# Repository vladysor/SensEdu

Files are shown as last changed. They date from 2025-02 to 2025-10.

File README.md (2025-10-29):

<p align="center">
  
</p>

<p align="center"><b>Ultrasonic Ranging & Detection Development Shield for Arduino GIGA R1</b><br>
Designed for education - easy entry into ultrasonic sensing and research</p>

<p align="center">
  <a href="https://github.com/ShiegeChan/SensEdu/releases/" target="_blank">
    
  </a>
  <a href="https://github.com/ShiegeChan/SensEdu/commits/main" target="_blank">
    
  </a>
</p>

<b>
<p align="center">
	<a href="https://github.com/ShiegeChan/SensEdu/releases" target="_blank">Download</a> ·
	<a href="https://shiegechan.github.io/SensEdu/getting-started/" target="_blank">Getting Started</a> ·
	<a href="https://shiegechan.github.io/SensEdu/projects/" target="_blank">Example Projects</a> ·
	<a href="https://shiegechan.github.io/SensEdu/" target="_blank">Documentation</a> ·
	<a href="https://shiegechan.github.io/SensEdu/contributing/" target="_blank">Contribution</a>
</p>
</b>

## Features

* **Custom Shield Design** for <a href="https://docs.arduino.cc/hardware/giga-r1-wifi/?queryID=undefined" target="_blank">Arduino GIGA R1 WiFi</a> and mechanically compatible boards (e.g., <a href="https://www.infineon.com/evaluation-board/KIT-A2G-TC375-ARD-SB" target="_blank">AURIX™ TC375 Shieldbuddy</a>). It extends the board with sensors:
  * **4x Infineon MEMS microphones**: capable of operating in ultrasonic range at approx. 20-80 kHz (<a href="https://www.infineon.com/assets/row/public/documents/24/49/infineon-im73a135-datasheet-en.pdf" target="_blank">datasheet</a>).
  * **2x Ultrasonic Transducers**: transmit ultrasonic waves with a center frequency of ~33kHz (<a href="https://www.farnell.com/datasheets/4413630.pdf?_gl=1*1fltz5c*_gcl_au*MTQwMTY3ODgxOC4xNzI2NDc2MDYw" target="_blank">datasheet</a>).
  * **2x Instrumentation Amplifiers**: providing 4x channels total, routed to external pin headers for connecting additional sensors such as surface EMG electrodes (<a href="https://www.analog.com/media/en/technical-documentation/data-sheets/ad8222.pdf" target= "_blank">datasheet</a>).
  * **1x Infineon Barometric Air Pressure Sensor**: provides pressure and temperature measurements; ideal for indoor and outdoor navigation, weather stations, drones, and more (<a href="https://www.infineon.com/dgdl/Infineon-DPS310-DataSheet-v01_02-EN.pdf?fileId=5546d462576f34750157750826c42242" target="_blank">datasheet</a>).
* **Low-Level SensEdu Library** for Arduino GIGA R1 that serves as a basic abstraction layer for the STM32H747 peripherals and provides default configurations for all sensors. It is implemented at the register level based on <a href="https://www.st.com/resource/en/reference_manual/rm0399-stm32h745755-and-stm32h747757-advanced-armbased-32bit-mcus-stmicroelectronics.pdf" target="_blank">STM32H747 Reference Manual</a> and <a href="https://developer.arm.com/documentation/ddi0403/latest/" target="_blank"> Armv7-M Architecture Reference Manual</a>, ensuring simplicity and expandability. Extensive examples are included to demonstrate library's functionality.
* **Example projects** show how to use SensEdu to achieve your learning goals. See the full implementation for pulsed time-of-flight distance measurements, FMCW ranging, FSK-modulated communication, a weather station, and other projects.
* **MATLAB scripts** enable visualization and post-processing of recorded data transferred via USB or Wi-Fi.

## Preview

<p align="center" style="margin:0">
  
  
  
  
  
</p>

## Installation

1. Download the latest release version from the <a href="https://github.com/ShiegeChan/SensEdu/releases" target="_blank">Download page</a>.
2. Extract the downloaded files and place the **libraries** folder into: `C:\Users\your_username\Documents\Arduino\`.
3. The **projects** folder can be placed anywhere in your system.
4. Open the <a href="https://www.arduino.cc/en/software" target="_blank">Arduino IDE</a> and install **Arduino Giga R1 board package** via the Boards Manager.

<p align="left" style="margin:0">
  
</p>
<p align="left" style="margin:0">
  
</p>

## Starting a Project

To get started, you can explore the hardware interface by following the examples provided in the SensEdu library (`Arduino\libraries\SensEdu\examples\`). A detailed description of all functions can be found in the <a href="https://shiegechan.github.io/SensEdu/library/" target="_blank">Documentation</a> under the "SensEdu Library" section.

In the `projects/` directory, you will find several complete projects designed for this board, including:
* **Ultrasonic Pulse-Echo Ranging**
* **Ultrasonic Pulse-Echo Ranging with Wi-Fi + GUI** - *in progress (25%)*
* **Ultrasonic Chirp Generation**
* **Ultrasonic FMCW Ranging**
* **Ultrasonic Doppler Velocimeter** - *coming soon*
* **Ultrasonic FSK Communication Link** - *coming soon*
* **EMG BioInputs** - *in progress (75%)*
* **Weather Station** - *in progress (50%)*

Detailed overview for each project is available in the "Projects" section of the <a href="https://shiegechan.github.io/SensEdu/projects/" target="_blank">Documentation</a>.

## Support

If you would like to contribute, please open a pull request!
Suggest improvements or check out already opened <a href="https://github.com/ShiegeChan/SensEdu/issues" target="_blank">issues</a> to help fix bugs or add new features.

## Acknowledgments

SensEdu was made possible thanks to these freely available tools:

* [Arduino] and [Arduino IDE 2.x]
* [XENSIV™ Digital Pressure Sensor Arduino Library]
* [STM32H747 Documentation] and [STM32CubeMX]
* [Jekyll] and [Just the Docs] template
* [KiCAD]

## License

* [**GPL-3.0 license**](https://github.com/ShiegeChan/SensEdu/blob/main/LICENSE)

[Arduino IDE 2.x]: https://github.com/arduino/arduino-ide
[Arduino]: https://www.arduino.cc/
[XENSIV™ Digital Pressure Sensor Arduino Library]: https://github.com/Infineon/arduino-xensiv-dps3xx
[STM32H747 Documentation]: https://www.st.com/en/microcontrollers-microprocessors/stm32h747-757/documentation.html
[STM32CubeMX]: https://www.st.com/en/development-tools/stm32cubemx.html
[Jekyll]: https://jekyllrb.com/
[Just the Docs]: https://github.com/just-the-docs/just-the-docs/tree/main
[STM32H747]: https://www.st.com/en/microcontrollers-microprocessors/stm32h747-757.html
[Arduino GIGA R1 WiFi]: https://docs.arduino.cc/hardware/giga-r1-wifi/
[KiCad]: https://www.kicad.org/

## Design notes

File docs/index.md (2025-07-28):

---
title: Introduction
layout: home
nav_order: 1
description: "SensEdu is an educational development shield for Arduino GIGA R1 used for RADAR and communications applications."
permalink: /
---

# Introduction
{: .fs-8 .fw-500}

Welcome to the SensEdu documentation!
{: .fs-6 .fw-400}
---

SensEdu is an educational project designed to simplify entry into RADAR and communications research.
{: .fw-500}

Based on the [STM32H747] Microcontroller and runs on the [Arduino GIGA R1 WiFi] development Board, providing industry-standard embedded development experience while remaining beginner-friendly. SensEdu is perfect for students looking for a smooth introduction to this field, offering an easy-to-understand yet highly modifiable software and hardware environment. 

This project is completely open source and comes with quick support from the development team.

{: .WARNING}
SensEdu is still in its early development stages.
The core functionality is available, but many additional features are in progress. If you like the project, consider [contributing]({% link Contributing/index.md %}). Any input from both experienced developers and beginners is highly appreciated!

## Features
{: .fw-500}

SensEdu includes:
{:.mb-1 .mt-3}
* MEMS microphones
* Barometric Air Pressure Sensor
* Ultrasonic Transducers

You can find detailed information about each component in the [PCB Chapter]({% link PCB/index.md %}). With these components, you can build a variety of projects, such as:
* Ultrasonic Distance Measurements
* Chirp Signal Generation
* FMCW Radars
* Frequency Shift Keying (FSK) communication between multiple boards
* Weather Stations

## Project Structure
{: .fw-500}

The project is divided into three main parts:

* [Shield PCB]({% link PCB/index.md %}) – Located in `pcb\`
* [Hardware Abstraction Library]({% link Library/index.md %}) – Located in `libraries\SensEdu\`
* [Full Projects]({% link Projects/index.md %}) – Located in `projects\`

Each part is thoroughly documented in this wiki, allowing you to modify both software and hardware using the provided examples.

## Acknowledgments
{: .fw-500}

SensEdu was made possible thanks to these freely available tools:
{: .mb-1}
* [Arduino] and [Arduino IDE 2.x]
* [XENSIV™ Digital Pressure Sensor Arduino Library]
* [STM32H747 Documentation] and [STM32CubeMX]
* [Jekyll] and [Just the Docs] template
* [KiCAD]

Thank You to All Contributors!
{: .fw-500 .mb-1}

<ul class="list-style-none">
{% for contributor in site.github.contributors %}
  <li class="d-inline-block mr-1">
     <a href="{{ contributor.html_url }}">{{ contributor.login }}</a>
  </li>
{% endfor %}
</ul>

[Arduino IDE 2.x]: https://github.com/arduino/arduino-ide
[Arduino]: https://www.arduino.cc/
[XENSIV™ Digital Pressure Sensor Arduino Library]: https://github.com/Infineon/arduino-xensiv-dps3xx
[STM32H747 Documentation]: https://www.st.com/en/microcontrollers-microprocessors/stm32h747-757/documentation.html
[STM32CubeMX]: https://www.st.com/en/development-tools/stm32cubemx.html
[Jekyll]: https://jekyllrb.com/
[Just the Docs]: https://github.com/just-the-docs/just-the-docs/tree/main
[STM32H747]: https://www.st.com/en/microcontrollers-microprocessors/stm32h747-757.html
[Arduino GIGA R1 WiFi]: https://docs.arduino.cc/hardware/giga-r1-wifi/
[KiCad]: https://www.kicad.org/

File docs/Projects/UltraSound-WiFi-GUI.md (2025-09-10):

---
title: Ultrasonic Ranging WiFi GUI
layout: default
math: mathjax
parent: Projects
nav_order: 2
---

# Ultrasonic Ranging WiFi GUI
{: .no_toc .fs-8 .fw-500}
---

{: .WARNING}
This project is in an early draft state. The WiFi GUI currently supports only raw data streaming with the provided Arduino WiFi example. Many UI elements are placeholders and non-functional.

- TOC
{:toc}

## Introduction

For the whole ultrasonic implementation info etc, refer to main [Ultrasonic Ranging page]({% link Projects/UltraSound.md %}). This page focuses on differences: WiFi implementation and GUI.

## Current status
A draft GUI (WiFi_GUI.mlapp) is now included. In its current form, the GUI works with the **UltraSound-WiFi-GUI**, but displays only raw signals. The GUI application will need to be adapted to get the full detailed readings.

Functional UI elements:
  - IP Address text field (to target the device on the network)
  - Start and Stop buttons (begin/end raw data streaming)
  - Main Axes (live plot for incoming raw data)

The other UI elements are non-functional dupes and will still have to be implemented.

TO DO: 
 - Filtered / XCORR / Distance buttons
 - CLI for outputs
 - simple / detailed data transmission
 - save plots / data
 - proper axis names
 - if the data is not received due to poor connection, don't crash the app, just skip one iteration and clean the buffers

Current draft:
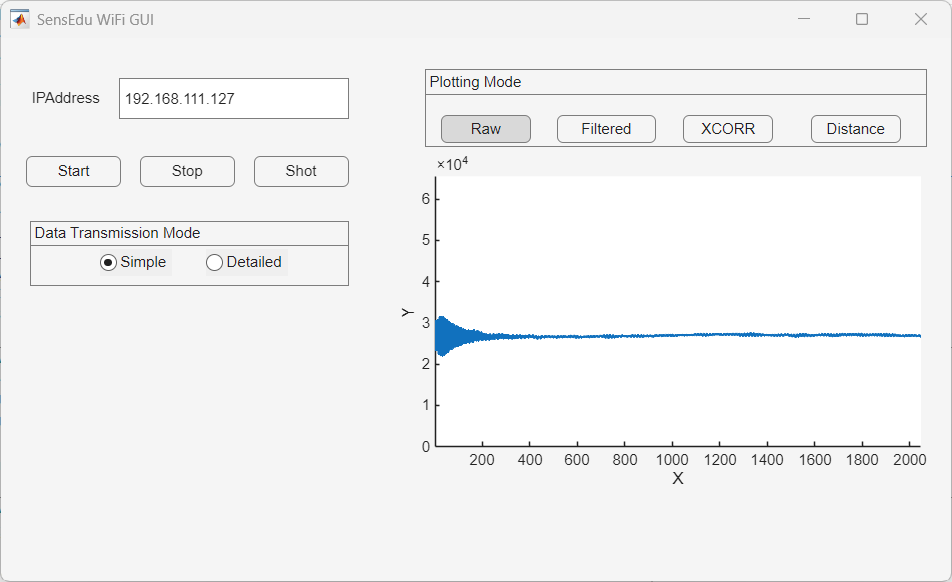
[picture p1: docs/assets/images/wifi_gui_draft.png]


Full planned sketch:
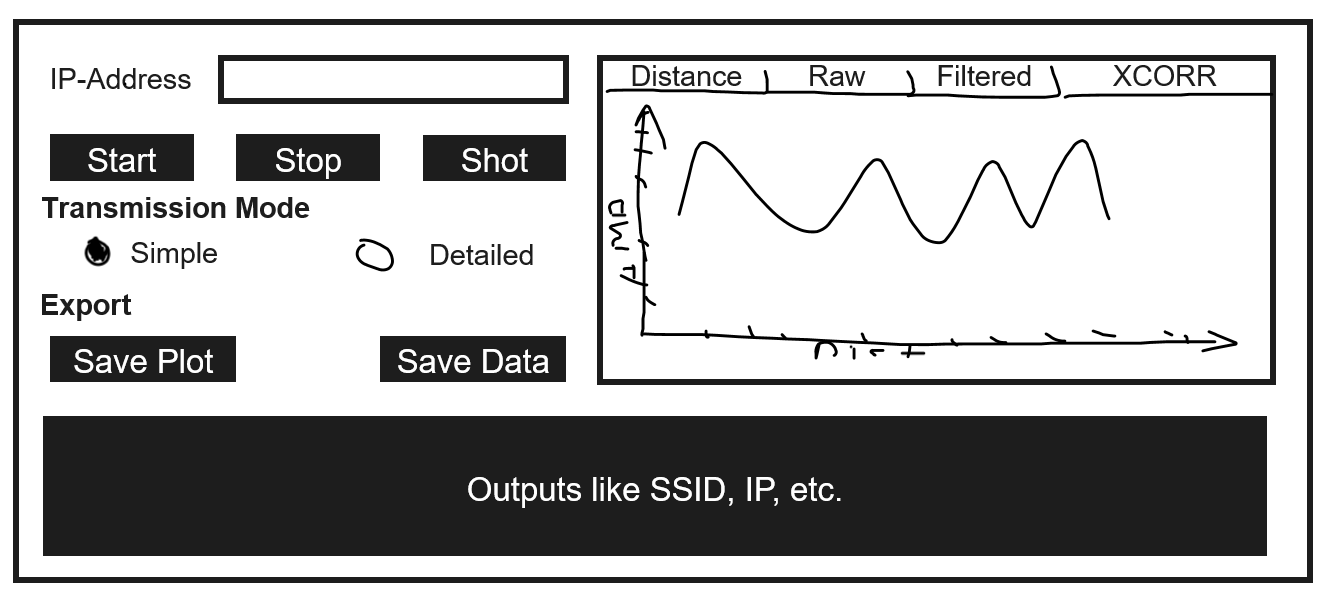
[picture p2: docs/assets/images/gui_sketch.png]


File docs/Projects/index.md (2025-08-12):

---
title: Projects
layout: default
nav_order: 5
permalink: /projects/
---

# Projects developed with SensEdu
{: .fs-8 .fw-500}
---

The following section documents select projects developed by SensEdu contributors. These real-world examples demonstrate practical use cases of the platform and highlight its capabilities.
{: .fw-500}

{: .WARNING}
Currently, this section is the main focus of our team. We aim to expand our collection of polished, fully documented projects to better illustrate SensEdu applications. Contributions are highly welcomed! If you’ve created a nice project, please consider adding it to both this wiki and our main repository by following [these guidelines]({% link Contributing/projects.md %}).

{: .NOTE}
Most of the projects utilize SensEdu library, but it is not explicitly necessary, you can develop projects with standard or other custom Arduino GIGA R1 libraries.

As detailed in the [PCB specifications]({% link PCB/index.md %}), all applications center around three core hardware components:
* MEMS microphones
* Barometric Air Pressure Sensor
* Ultrasonic Transducers

### Ultrasonic Transceiver
SensEdu’s primary functionality lies in its *ultrasonic transceiver* capabilities. The system pairs 32 kHz ultrasonic transmitters (speakers) with high-sensitivity MEMS microphones optimized for 10-100 kHz reception (32 kHz resonant frequency). This combination enables implementations such as:
* Distance measurements
* Collision avoidance systems
* Robotic navigation
* Radars
* Radio communication

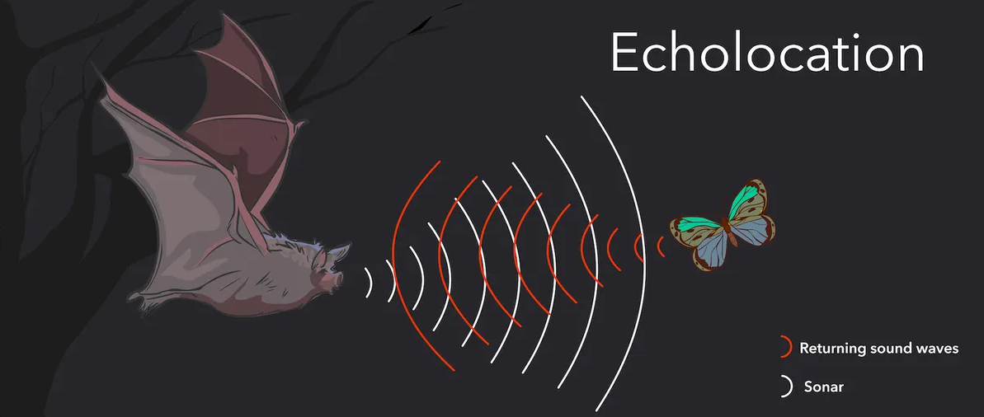
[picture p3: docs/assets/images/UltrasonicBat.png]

{: .text-center .mb-1}

Biological inspiration: Bat echolocation using ultrasonic waves (Image source: [BBC Science Focus]).
{: .mt-1}

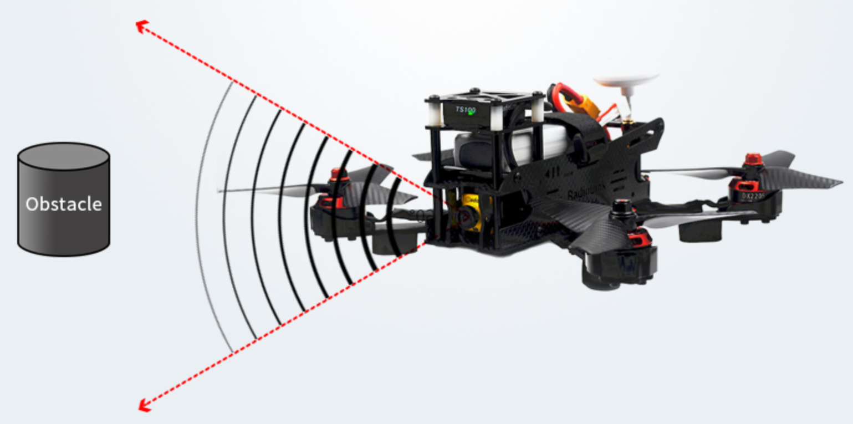
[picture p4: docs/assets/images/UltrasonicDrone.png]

{: .text-center .mb-1}

Modern application: Drone obstacle detection systems (Image source: [Microcontrollertips]).
{: .mt-1}

### Barometric Pressure Sensor
Moreover, the board is equipped with a *barometric sensor* which enables atmospheric measurements. It could be utilized for:
* Elevation tracking (climbing\descent detection)
* Environmental monitoring systems
* Motion pattern recognition (e.g., falling)
* Robot vertical navigation

### General Purpose Instrumentation Amplifiers
SensEdu is equipped with extra x2 dual-channel amplifiers [AD8222](https://www.analog.com/media/en/technical-documentation/data-sheets/ad8222.pdf). Their inputs are wired to headers, making them suitable for any application that requires a simple Amplification → ADC signal path. This is the final piece that makes SensEdu an excellent tool for basic sensor systems education, enabling a wide range of projects such as:
* Various bio-signals projects, e.g., Electromyography (EMG)
* Strain Gauge Measurements
* Thermocouple Measurements

[BBC Science Focus]: https://www.sciencefocus.com/nature/how-does-echolocation-work
[Microcontrollertips]: https://www.microcontrollertips.com/principle-applications-limitations-ultrasonic-sensors-faq/

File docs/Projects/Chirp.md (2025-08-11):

---
title: Chirp Signal Generation
layout: default
math: mathjax
parent: Projects
nav_order: 3
---

# Chirp Signal Generation
{: .no_toc .fs-8 .fw-500}
---

## Table of contents
{: .no_toc .text-delta }
1. TOC
{:toc}

## Introduction
{: .text-yellow-300}

The **Chirp Signal Generation Project**{: .text-green-000} aims at proviving basic code to generate **frequency modulated continuous waves (FMCW)** on the **SensEdu Shield**{: .text-green-000} using the **Arduino Giga R1**{: .text-green-000}. The projects provides two types of frequency modulation : **sawtooth** and **triangular**.

FMCW, also called chirp signals, are encountered in numerous fields, like radar & sonar systems, telecommunications, signal processing and more. You will find more information on the potential applications from our upcoming FMCW radar project.

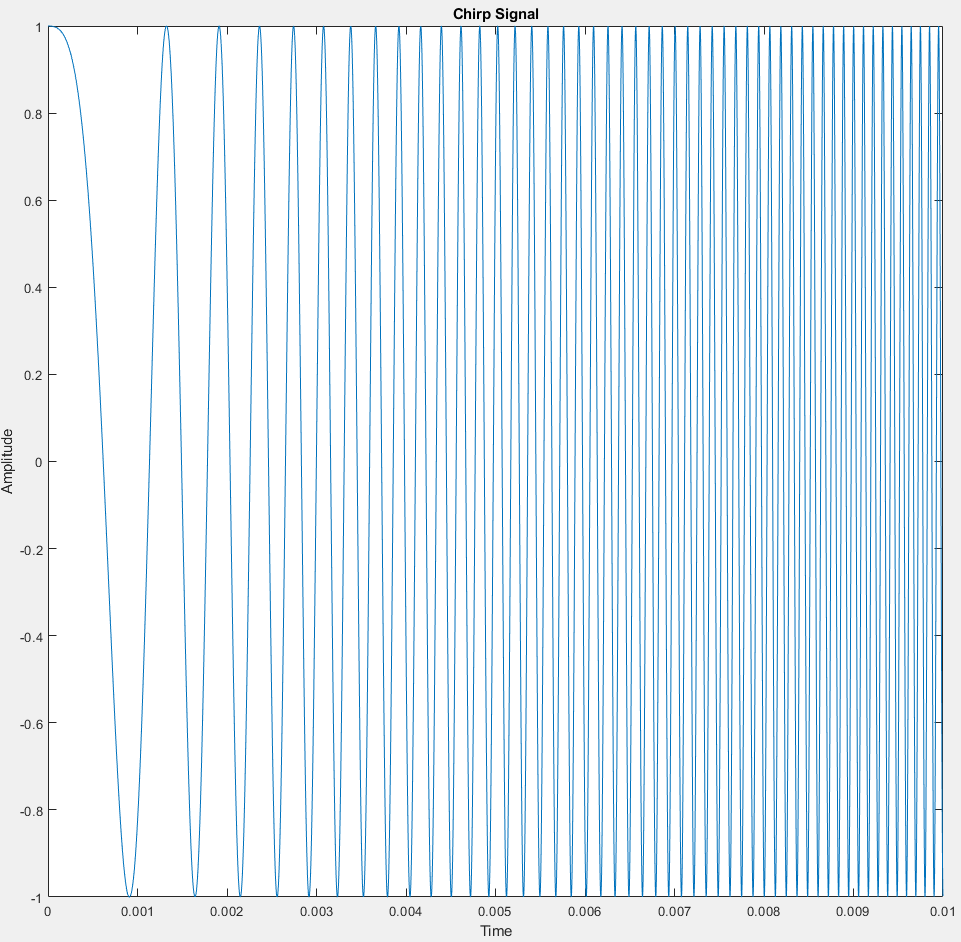
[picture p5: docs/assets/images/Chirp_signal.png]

{: .text-center}

_Chirp signal sweeping from 100 Hz to 10 kHz_
{: .text-center}

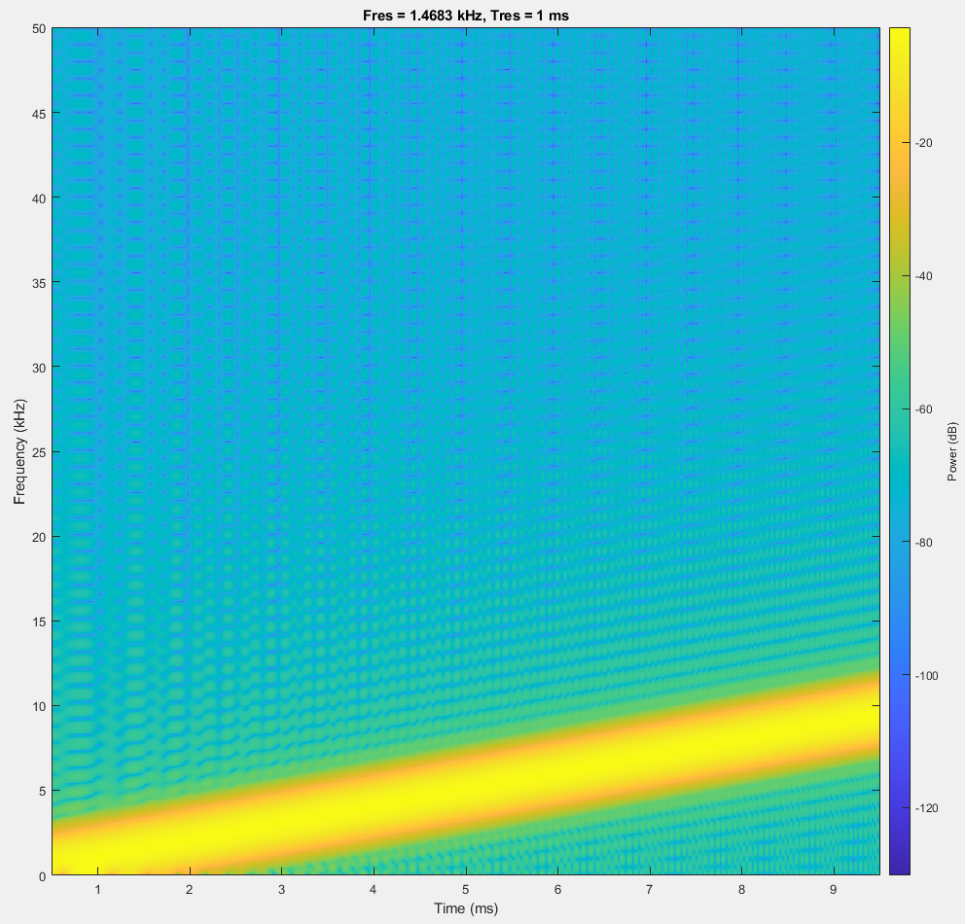
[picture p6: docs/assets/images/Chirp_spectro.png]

{: .text-center}

_Spectrogram of chirp sweeping from 100 Hz to 10 kHz_
{: .text-center .}

## Chirp Generation Function
{: .text-yellow-300}
Arduino does not provide any built-in chirp signal function. There are workarounds using MATLAB's built-in chirp function but our idea was to create this signal directly in Arduino with the SensEdu library.

The `generateSawtoothChirp` and `generateTriangularChirp` functions both calculate the values to generate a sawtooth chirp and triangular chirp respectively and copy these values to the DAC's buffer.

```c
void generateSawtoothChirp(uint16_t* array)
void generateTriangularChirp(uint16_t* array)
```

### Parameters
{: .text-yellow-100}
* `uint16_t* array` : A pointer to an array where the generated chirp signal will be stored.

### Description
{: .text-yellow-100}
The generate chirp functions use two arrays `lut_sine` and `vChirp` to calculate the chirp values :

* `lut_sine` is a LUT containing the values of a quarter sine wave. The `x` variable defines the resolution of `lut_sine`. A larger `x` will result in a more detailed LUT with more values which in turn increases the precision of the chirp values which will be calculated.
* `vChirp` is the array in which the chirp values are calculated.

The following steps describe how the function was implemented :

**Step 1**{: .text-blue-000} : Generate the quarter-wave LUT

```c
// Generate the quarter-wave sine LUT
    for (int i = 0; i < 90 * x; i++) {
        float phase_deg = (float)i * 90.0 / (90 * x); // Phase angle in degrees
        float phase_rad = phase_deg * Pi / 180.0; // Phase angle to radians
        lut_sine[i] = sin(phase_rad-Pi/2); // Store sine value in the LUT
    }
```

**Step 2**{: .text-blue-000} : Calculate the instantaneous phase of the chirp signal and wrap between 0-360 degrees

```c
for (int i = 1; i < samples_int + 1; i++) {
        float phase_rad = 2.0 * Pi * (0.5 * sK * (i - 1) / fs + START_FREQUENCY) * (i - 1) / fs; // Phase angle in radians
        float phase_deg = phase_rad * 180.0 / Pi; // Phase angle to degrees
        float phase_deg_wrapped = fmod(phase_deg, 360.0); // Wrap phase angle to 0-360 degrees
```

**Step 3**{: .text-blue-000} : Calculate the value of the chirp using a quadrant-based approach. Scale and offset values to get 12 bit values.

```c
if (phase_deg_wrapped <= 90) {
            vChirp[i - 1] = lut_sine[(int)(phase_deg_wrapped / 90.0 * (90 * x - 1))] * 2047.5 + 2047.5;
        } else if (phase_deg_wrapped <= 180) {
            vChirp[i - 1] = -lut_sine[(int)((180.0 - phase_deg_wrapped) / 90.0 * (90 * x - 1))] * 2047.5 + 2047.5;
        } else if (phase_deg_wrapped <= 270) {
            vChirp[i - 1] = -lut_sine[(int)((phase_deg_wrapped - 180.0) / 90.0 * (90 * x - 1))] * 2047.5 + 2047.5;
        } else {
            vChirp[i - 1] = lut_sine[(int)((360.0 - phase_deg_wrapped) / 90.0 * (90 * x - 1))] * 2047.5 + 2047.5;
        }
```

For the triangular modulation, the array values are mirrored on the other half.

```c
for (int i = samples_int; i < samples_int * 2; i++) {
        vChirp[i] = vChirp[samples_int * 2 - i - 1];    // Mirror the chirp signal
    }
```

{: .NOTE }
In this configuration, the first value of the chirp signal array is 0 (or 0 V in amplitude at DAC output). This initial value can be changed by modifying `sine_lut`.

**Step 4**{: .text-blue-000} : Copy the chirp signal's values to the DAC buffer

```c
// Copy the chirp signal to the DAC buffer
    for (int i = 0; i < samples_int; i++) {
        array[i] = (uint16_t)vChirp[i];
    }
```

---

## Main code
{: .text-yellow-300}
Check out the [DAC]({% link Library/DAC.md %}) section for more information on the DAC library and different DAC related functions.

The `Chirp_SawtoothMod.ino` and `Chirp_TriangularMod.ino` files contain the main code to generate the chirp signal, send the chirp signal to the DAC and enable the DAC.

The code contains the following user settings to adjust the chirp signal :

* `CHIRP_DURATION`{: .text-green-000} : The period of the chirp signal in seconds
* `START_FREQUENCY`{: .text-green-000} : The start frequency of the chirp signal in Hz
* `END_FREQUENCY`{: .text-green-000} : The end frequency of the chirp signal in Hz

A very important variable in the main code is the sampling frequency `fs`. Based on the Nyquist-Shannon sampling theorem, `fs` needs to be at least double the maximum frequency (or end frequency) of the chirp signal.
Keep in mind this sampling frequency will also be the DAC's output frequency in the `SensEdu_DAC_Settings` function.

{: .IMPORTANT }
`fs` needs to be at least 2*END_FREQUENCY in order for the chirp signal to be generated properly.

The `samples_int` is an integer representing the amount of samples for one period of the chirp signal. This value also represents the memory size in the `SENSEDU_DAC_BUFFER` and `SensEdu_DAC_Settings` functions.

The values of the chirp are printed in the serial monitor.
```c
// Print the chirp signal LUT
    Serial.println("start of the Chirp LUT");
    for (int i = 0 ; i < samples_int; i++) { // loop for the LUT size
        Serial.print("value ");
        Serial.print(i+1);
        Serial.print(" of the Chirp LUT: ");
        Serial.println(lut[i]);
    }
```

[example link]: https://github.com/ShiegeChan/SensEdu
[link1]: https://docs.github.com/en/get-started/writing-on-github/getting-started-with-writing-and-formatting-on-github/basic-writing-and-formatting-syntax
[link2]: https://just-the-docs.com/

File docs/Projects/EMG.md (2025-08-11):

---
title: EMG BioInputs
layout: default
parent: Projects
math: mathjax
nav_order: 5
---

# EMG BioInputs
{: .fs-8 .fw-500 .no_toc}
---

- TOC
{:toc}

## Introduction

[Electromyography](https://en.wikipedia.org/wiki/Electromyography) (EMG) is a widely-used technique for recording and analyzing electrical activities generated by skeletal muscles.

EMG is appealing due to its simplicity when detecting basic movements, such as a biceps contraction. For such projects, advanced hardware or complex signal processing is often unnecessary. This makes EMG an accessible tool for beginners as an introduction into biomedical engineering projects. Furthermore, the foundational concepts learned through EMG can be extended to related fields, including [Electrocardiography](https://en.wikipedia.org/wiki/Electrocardiography) (ECG), [Electrooculography](https://en.wikipedia.org/wiki/Electrooculography) (EOG), [Electroencephalography](https://en.wikipedia.org/wiki/Electroencephalography) (EEG), and others.

In SensEdu, we demonstrate how basic biceps contraction can be used to simulate keyboard press logic, with latency of ~100–200ms. We use the most basic circuit design combined with signal processing in MATLAB.

This page will guide you step-by-step through the required setup and knowledge to create a simple yet effective demonstration of a typical biomedical engineering project.

## Biological Background

First, we need to establish an understanding of what we are trying to measure.

{: .TIP}
Highly recommended watching the video [Neuromuscular Junction](https://youtu.be/_k6QINRcdV4?si=TG5Yw0wvDcTJtR6G) by [Byte Size Med].

The most important structure that we need to focus on is the [Neuromuscular Junction](https://en.wikipedia.org/wiki/Neuromuscular_junction) (NMJ). This is a specialized [synapse](https://en.wikipedia.org/wiki/Synapse) that acts as a communication bridge between [motor neurons](https://www.simplypsychology.org/motor-neuron.html) and skeletal muscle fibers. The NMJ plays a fundamental role in converting neural signals into muscle contraction. Let's break down its working principle step by step.

The process begins with a motor neuron transmitting an electrical signal called an [Action Potential]. This signal travels along neuron's [axon](https://en.wikipedia.org/wiki/Axon) until it reaches the NMJ. It activates **voltage-gated sodium channels**, which allow positively charged sodium ions (Na⁺) enter the cell. The influx of sodium causes the cell membrane to become *"less negatively charged"*, a change known as **depolarization**.

Continuous depolarization of the cell membrane subsequently activates **voltage-gated calcium channels**. Calcium ions (Ca²⁺) flow into the cell which triggers [little containers](https://en.wikipedia.org/wiki/Synaptic_vesicle) with [neurotransmitters](https://en.wikipedia.org/wiki/Neurotransmitter) to fuse with the membrane and release [Acetylcholine](https://en.wikipedia.org/wiki/Acetylcholine) (ACh).

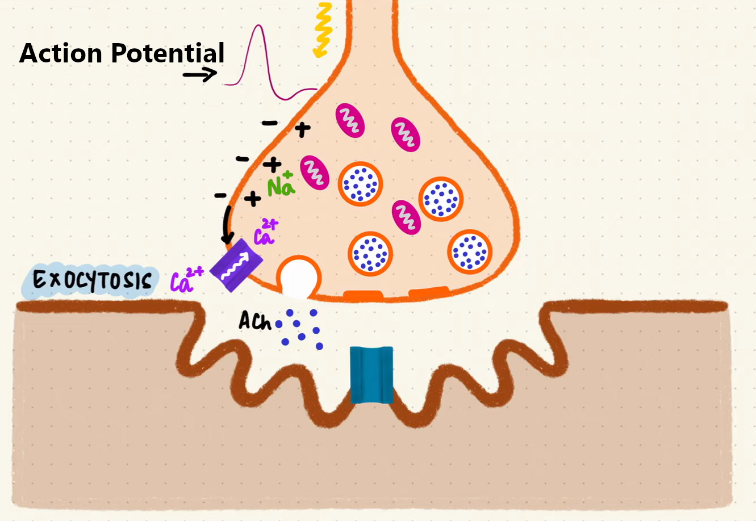
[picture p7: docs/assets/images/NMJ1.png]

{: .text-center .mb-1}

[Exocytosis](https://en.wikipedia.org/wiki/Exocytosis) process at the Neuromuscular Junction (source: [Byte Size Med])
{: .text-center .mt-0 .fw-500}

Acetylcholine travels across the synaptic space and binds to specialized receptors on the muscle cell's membrane. These receptors, also known as [ligand-gated ion channels](https://en.wikipedia.org/wiki/Ligand-gated_ion_channel), respond to the chemical messenger (neurotransmitter) by opening and allowing ions to enter the muscle cell. This process triggers membrane **depolarization**, causing the resting membrane potential of the muscle cell (normally at around -90mV) to become less negative.

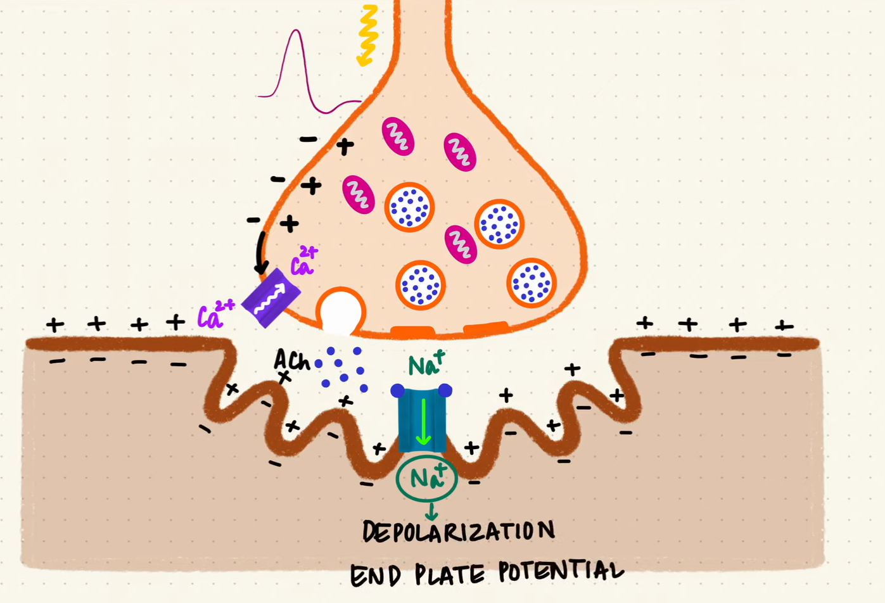
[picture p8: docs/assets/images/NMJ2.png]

{: .text-center .mb-1}

[Depolarization](https://en.wikipedia.org/wiki/Depolarization) caused by the opening of ligand-gated ion channels (source: [Byte Size Med])
{: .text-center .mt-0 .fw-500}

As more ACh molecules bind to their receptors, the membrane voltage continues to rise. Once it reaches a threshold of approximately -50 mV, **voltage-gated sodium channels** open, allowing sodium ions (Na⁺) to rush into the muscle cell. This influx of sodium completes the process of membrane depolarization and generates an **Action Potential**. This electrical signal propagates along the muscle membrane, eventually leading to a muscle contraction.

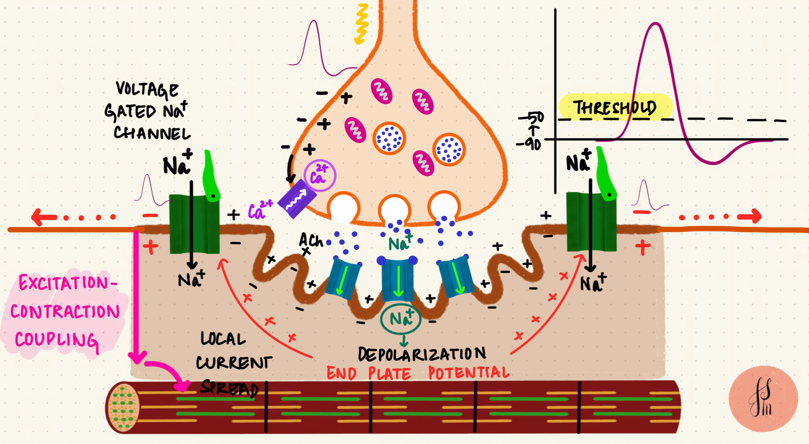
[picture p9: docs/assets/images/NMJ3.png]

{: .text-center .mb-1}

[Excitation-Contraction Coupling](https://www.sciencedirect.com/topics/medicine-and-dentistry/excitation-contraction-coupling) (source: [Byte Size Med])
{: .text-center .mt-0 .fw-500}

{: .NOTE}
If you feel overwhelmed by the details, the main takeaway: a neural electrical signal is converted to a chemical signal and then back into electrical signal in the muscle. The sequence **Neural Action Potential** → **Acetylcholine Release** → **Muscle Action Potential**. The muscle action potential then propagates along the muscle cell membrane and ultimately triggers muscle contraction.<br><br>The most important point is that this **muscle action potential can be measured**, providing valuable information about muscle activity.

## Recording Action Potentials

Action Potentials can be recorded using different methods:
* **Invasive Needle EMG**: Inserting electrodes directly into the muscle, enabling highly precise and localized recordings. It is widely used in clinical applications and treatments where precision and measurement quality are critical.
* **Non-invasive Surface EMG**: Placing electrodes on the skin above the muscle. This approach improves patient comfort and simplifies repeatable studies, making it ideal for educational purposes. However, sEMG has significant precision **limitations due to the layers of skin and fat** between the electrodes and the muscle. These limitations make it challenging to differentiate the activity of individual muscle fibers and to record signals from small muscles, like ones around the fingers.

{: .NOTE}
In SensEdu we use surface EMG. From now on, whenever we mention EMG or electrodes, we are referring to sEMG and surface electrodes, respectively.

## Hardware Setup

This section describes the necessary connections and hardware details required for the proper setup of the EMG BioInputs system and writing the script for MCU. Below is an illustration of the overall system architecture.

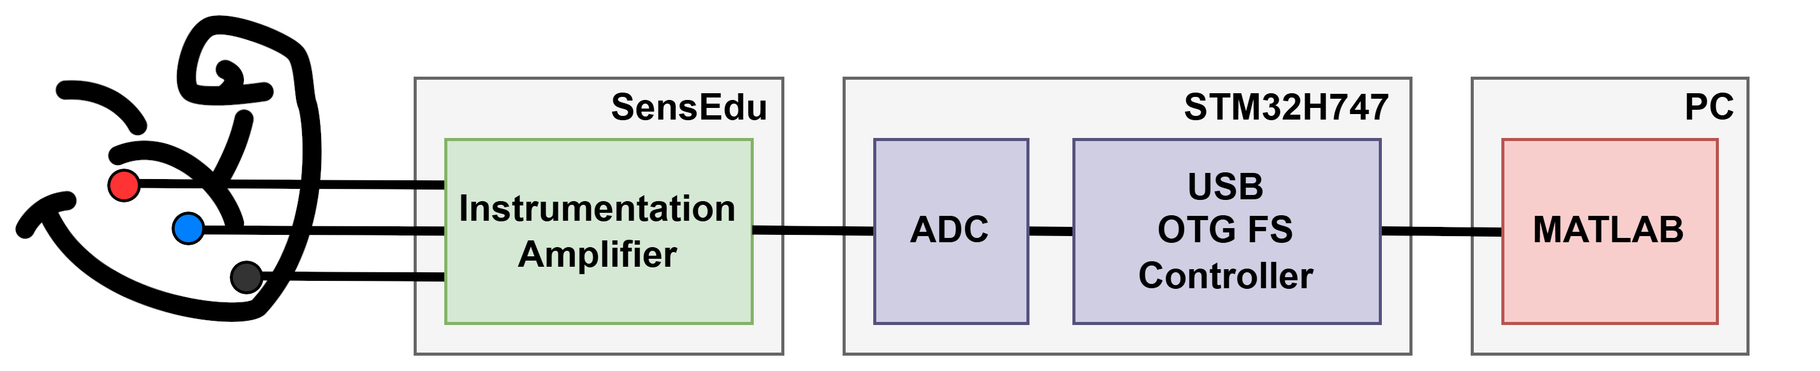
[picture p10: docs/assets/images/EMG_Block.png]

{: .text-center .mb-1}

EMG BioInputs System Architecture
{: .text-center .mt-0 .fw-500}

### Electrodes Connectivity

The system supports **up to 4 EMG probes**, which can be connected via female 4-Pin 2.54 headers: **J9**, **J11**, **J12**, and **J20**. 

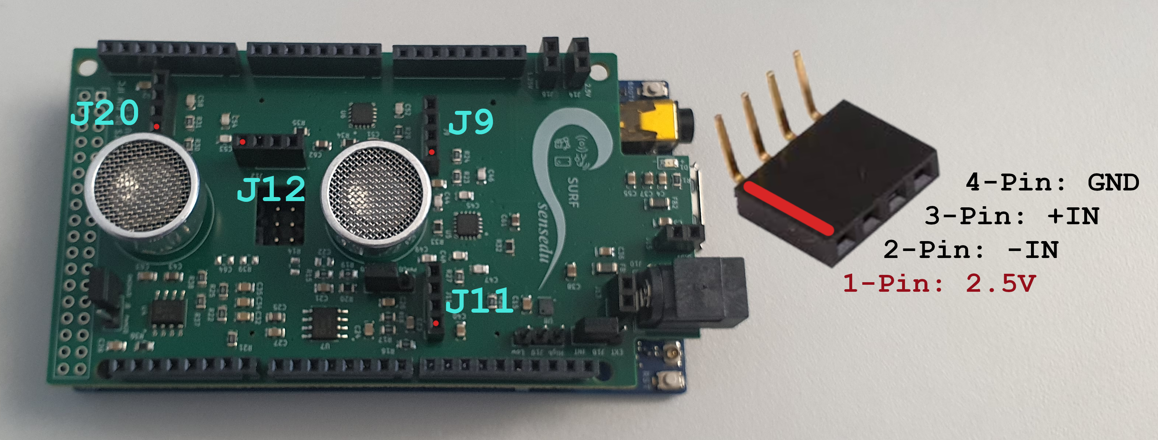
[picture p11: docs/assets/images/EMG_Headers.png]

{: .text-center .mb-1}

SensEdu input headers (red dots mark the 1st pin)
{: .text-center .mt-0 .fw-500}

A typical electrode consists of 3 connectors: **Reference**, **Positive Input**, and **Negative Input**. Below is a table detailing how these connectors correspond to the pins on the headers. Note that the voltage pin (1st pin) on the headers is not used in this connection.

| Electrode Connector | Signal | Header Pin |
|:---|:---|:---|
| Negative Input | –IN  | 2nd Pin |
| Positive Input | +IN  | 3rd Pin |
| Reference | GND  | 4th Pin |

{: .WARNING}
Most commercially available electrodes use connectors that are not directly compatible with typical 2.54 headers. For specific chosen electrode you will need a solution how to make this connection possible via soldering, custom adapters, or ready-made solutions.

In our example, we used the following electrodes:

| Manufacturer | Product Title | Product Code | Datasheet | Store |
|:---|:---|:---|:---|:---|
| SparkFun Electronics | Electrode Pads | 12970 | [link](https://mm.digikey.com/Volume0/opasdata/d220001/medias/docus/2277/CAB-12970_Web.pdf) | [link](https://www.digikey.at/de/products/detail/sparkfun-electronics/12970/6833933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) |
| MTG Imiella Medizintechnik | Liquid Gel Disposable Electrodes for ECG (Ø40mm) | S40LG | [link](https://static.mercateo.com/ec/2c36d66dd9904e92ad9e3075734affb2/pdf/106366.pdf?v=2297) | [link](https://www.mercateo.at/p/2768-028002/Einmal_Klebeelektroden_40_mm_Liquid_Gel_30_Stueck.html) |

These electrodes use a mini-jack connector. To simplify the connection, we designed a simple PCB adapter called **MiniJack2Jumper**. This adapter is inserted vertically into the SensEdu header, providing a mini-jack socket and eliminating the need for soldering. All PCB source files, including Gerbers and BOM, are available in the directory: `/Projects/EMG-BioInputs/pcbs/MiniJack2Jumper`. To replicate our setup, you can use archive `MiniJack2Jumper/manufacturing/MiniJack2Jumper-Gerber.zip` to order the PCB from any cheap Chinese manufacturer. The cost typically ranges from $15–$30 depending on shipping.

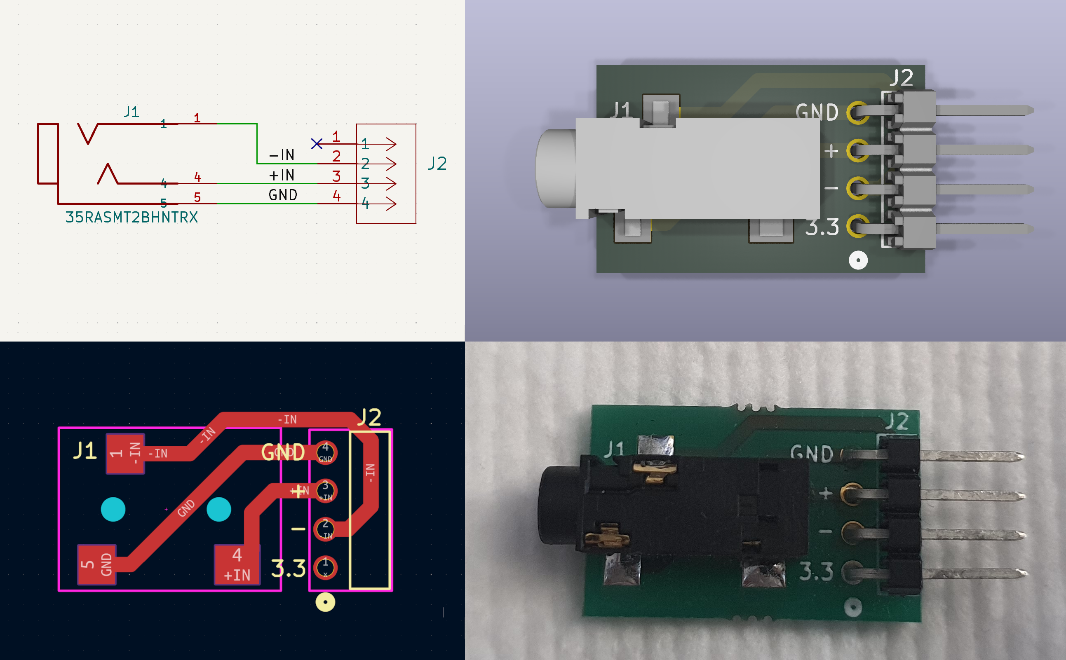
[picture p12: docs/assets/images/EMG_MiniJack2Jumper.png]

{: .text-center .mb-1}

MiniJack2Jumper adapter: Schematics, PCB view, 3D view, and real-life view
{: .text-center .mt-0 .fw-500}

After connecting the electrodes using the MiniJack2Jumper adapter, the final setup looks as follows:


{: .text-center .mb-1}

Electrode connection to SensEdu
{: .text-center .mt-0 .fw-500}

### Amplifier Circuit

The first stage after the input electrodes is signal amplification. 

The idea is to detect a signal at two points, amplify the "difference", and remove everything "common" between them. This way, the local EMG signal will be isolated and amplified. For that, we need a differential amplifier with a **high Common Mode Rejection Ratio** (CMRR), at least >$$90dB$$. 

Besides CMRR, an amplifier is also required to have a **high input impedance**. The impedance of the electrode-skin interface can vary from several thousand ohms to several megohms for dry skin. In order to prevent attenuation and distortion of the detected signal due to the effects of input loading, the input impedance of the differential amplifier should be as large as possible.

A differential amplifier with input buffer amplifiers, which features very high CMRR and input impedance, is called an [Instrumentation Amplifier](https://en.wikipedia.org/wiki/Instrumentation_amplifier). SensEdu is equipped with this type of amplifiers, specifically the x2 dual-channel [AD8222](https://www.analog.com/media/en/technical-documentation/data-sheets/ad8222.pdf), making the platform suitable for bio-signal measurements.

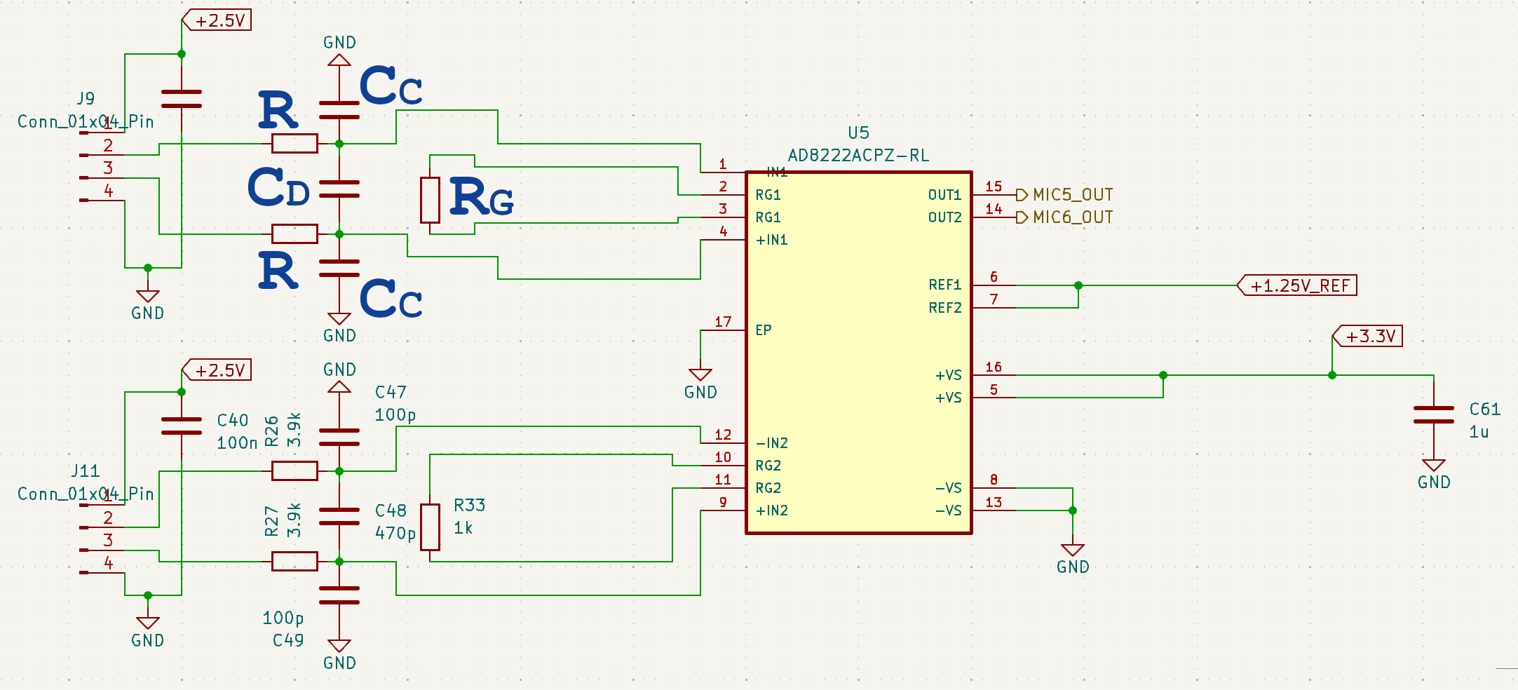
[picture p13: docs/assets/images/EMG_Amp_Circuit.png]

{: .text-center .mb-1}

Amplification Circuit
{: .text-center .mt-0 .fw-500}

Gain is set by $$R_G$$ resistor, using the following formula:

$$G = 1 + \frac{49.4kΩ}{R_G} = 1 + \frac{49.4kΩ}{1kΩ} = 50.4$$

To avoid high frequency rectification and thus signal distortions, additional filtering is applied at the input. The filter limits the input signal bandwidth according to the following relationships:

$${f_c}_{DIFF} = \frac{1}{2\pi × R(2C_D + C_C)} = \frac{1}{2\pi × 3.9kΩ(2×470pF + 100pF)} = 37.7\mathrm{kHz}$$

$${f_c}_{CM} = \frac{1}{2\pi × R × C_C} = \frac{1}{2\pi × 3.9kΩ × 100pF} = 392.2\mathrm{kHz}$$

{: .NOTE}
Mismatch between $$R × C_C$$ at the positive and negative inputs degrades the CMRR of the AD8222. By using a value for $$C_D$$ that is ~10× larger than $$C_C$$, the effect of the mismatch is reduced and performance is improved.

We used the default $${f_c}_{DIFF}$$ and $${f_c}_{CM}$$ cutoff frequencies for all projects, which were originally selected to suit the ultrasonic use case. Additional optimization is possible by reducing these cutoff frequencies to align with the working range of EMG signals (up to ~$$500\mathrm{Hz}$$). It could result in improved signal quality and reduced post‐processing requirements.

To write Arduino scripts for EMG signal acquisition, it is crucial to understand how the amplifier I/O is wired. Specifically, the following details:
* Which input header is connected to each amplifier channel
* Which amplifier output corresponds to which ADC channel on the MCU

All these details are available in the [SensEdu schematics](https://github.com/vladysor/SensEdu/blob/main/pcb/SensEdu_Schematics.pdf) and [ADC mapping table]({% link Library/ADC.md %}#adc_mapping). For convenience, the table below provides a summary of the relevant connections:

| Input Header | Amplifier Channel | Output Arduino Pin | Output STM32 Pin | Available ADCs
|:---|:---|:---|:---|:---|
| J9 | U5 CH1  | A0 | PC4 | ADC1 & ADC2 |
| J11 | U5 CH2  | A2 | PB0 | ADC1 & ADC2 |
| J12 | U6 CH1  | A11 | PA0_C | ADC1 & ADC2 |
| J20 | U6 CH2  | A7 | PA0 | ADC1 |

### Data Acquisition

The next step is to write and configure the Arduino sketch responsible for data acquisition. This involves configuring ADC parameters, such as sampling rate, buffer size, memory mode, etc.

For EMG, a sampling rate of about $$1.5\mathrm{kHz}$$ is usually sufficient. However, to improve the quality of future digital post-processing, this project uses a high oversampling rate of $$f_s = 25.6\mathrm{kHz}$$. Each channel uses a buffer of $$N_s = 1024 \ \mathrm{samples}$$. ADC is configured with DMA to minimize CPU load and maximize performance. The ideal theoretical duration of one complete measurement cycle is given as:

$$d_{meas, \ ideal} = \frac{N_s}{f_s} = \frac{1024 \ \mathrm{samples}}{25.6\mathrm{kHz}} = 40\mathrm{ms} $$

{: .NOTE}
The measurement duration is independent of the number of selected channels. ADC is designed to maintain its sampling frequency **per channel**.

In practice, the actual $$d_{meas}$$ varies between approximately $$46-51\mathrm{ms}$$ due to delays from data transmission, wasted CPU cycles, ADC conversion rate fluctuations, and other factors. In the end, it results in a practical measurement rate at around $$20$$ measurements per second. If this performance is not satisfactory, revisit the adjustment of ADC parameters.

Keeping selected parameters in mind, the ADC can be configured using [SensEdu Library]({% link Library/index.md %}). The configuration follows similar structure to the [Read_ADC_3CH_DMA]({% link Library/ADC.md %}#read_adc_3ch_dma) example. Below is a minimal code example, focusing on the essential lines.

```c
ADC_TypeDef* adc = ADC1;
const uint16_t channel_count = 4;
uint8_t adc_pins[channel_count] = {A0, A2, A11, A7};
const uint16_t sampling_rate = 25600;

const uint16_t mem_size = 16 * channel_count * 64; // must be a multiple of 16
__attribute__((aligned(__SCB_DCACHE_LINE_SIZE))) uint16_t emg_data[mem_size];

SensEdu_ADC_Settings adc_settings = {
    .adc = adc,
    .pins = adc_pins,
    .pin_num = channel_count,

    .conv_mode = SENSEDU_ADC_MODE_CONT_TIM_TRIGGERED,
    .sampling_freq = sampling_rate,
    
    .dma_mode = SENSEDU_ADC_DMA_CONNECT,
    .mem_address = (uint16_t*)emg_data,
    .mem_size = mem_size
};
```

Once the parameters are selected, the ADC must be initialized, enabled, and started.

```c
void setup() {
    Serial.begin(115200);
    SensEdu_ADC_Init(&adc_settings);
    SensEdu_ADC_Enable(adc);
    SensEdu_ADC_Start(adc);
}
```

In the main loop, ensure that ADC completed its conversions and that DMA transferred the data. Transfer the data to PC, and restart the ADC again.

```c
void loop() {
    while(!SensEdu_ADC_GetTransferStatus(adc));
    transfer_serial_data(&(emg_data[0]), mem_size, 64);

    SensEdu_ADC_ClearTransferStatus(adc);
    SensEdu_ADC_Start(adc);
}
```

The final expanded sketch is available at `/projects/EMG-BioInputs/EMG-BioInputs.ino`. It differs from above snippets in that it sends all configuration data to MATLAB during initialization. Additionally, the measurement process is triggered by MATLAB at each iteration to simplify data synchronization.

### Data Transfer

Arduino GIGA R1 doesn't use a typical UART interface for serial communication. Instead, it uses USB communication abstracted to behave like a serial link. This implementation makes the connection baud rate independent, meaning the number in `Serial.begin()` has no effect on the actual transfer speed. For further details on the USB implementation, refer to Figure 793 (Page 2747) of [STM32H747 Reference Manual] (OTG_FS) and the USB0 in the [Arduino GIGA R1 Schematics]. 

**To maximize the USB efficiency, data should be arranged and transferred in chunks**. Based on tests in [this repository](https://github.com/vladysor/giga-r1-serial-transfer-tests), the optimal chunk size is 64 bytes, as specified in the OTG_FS section of the reference manual. Below is an example of how to implement chunked data transfer via USB.

```c
// chunk_size in bytes, for OTG_FS "64" is passed
void transfer_serial_data(uint16_t* buf, const uint16_t buf_size, const uint16_t chunk_size) {
    for (uint16_t i = 0; i < (buf_size*2); i += chunk_size) {
        uint16_t cur_chunk_size = ((buf_size*2) - i < chunk_size) ? (buf_size*2 - i) : chunk_size;
        Serial.write((const uint8_t *) buf + i, cur_chunk_size);
    }
}
```

Alternatively, WiFi can be used for data transfer by implementing a method similar to the [Basic_UltraSound_WiFi]({% link Library/Others.md %}#basic_ultrasound_wifi) example.

## Signal Processing

EMG post-processing was made in MATLAB. You can find the main block diagram below. The main components of filtering contains of storing the data in a longer buffer, applying filtering, enveloping and making a decision based on the final processed data: either the button on the keyboartd is presed, hold or released.

[picture: block diagram]

### Problematic ADC Readings

First, let's discuss the incoming RAW data to MATLAB. There was noticed a weird behaviour with the first couple of samples at each measurement cycle. They always abnormally high and after 5-10 samples stabilized around expected values.

[picture: weired samples]

It is not certain what exactly causes this behaviour, most probably is high input capacitance to ADC due to using the electrodes and all this bio setup.

To fix it fast, script just removes the first 8 samples from each measurement cycle, using only stable ADC data, keep that in mind while calculating the sizes for next steps.

### The Buffer

After triggering the measurement cycle which lasts for $$d_{meas, ideal} = 40\mathrm{ms}$$, the incoming data is stored in a buffer that contains the whole **1 second** of these measurement cycles. Works like FIFO, the oldest measurement is out, the whole buffer shifts to the left and the freed up space is taken by the new one.

{: .NOTE}
The buffer size is calculated based on $$d_{meas, ideal}$$ which means that actual buffer contains data for a bit longer period than calculated.

Processing on this longer buffer helps multiple cycles of low-frequency components being captured and properly filtered out which improves filter's ability to attenuate noise and artifact and preservation of desired signal components.

A longer history allows low-pass filters (used in envelope detection) to smooth the rectified signal over a larger time frame, resulting in a more robust and stable envelope.

For example, a 5Hz low-pass filter requires at least 200ms of data for one full cycle. With a 1-second history, the envelope will be less sensitive to short-term fluctuations or noise.

Use a 1-second buffer for filtering and envelope detection, but process overlapping chunks (e.g., update every 40ms). This ensures that decisions are updated frequently without sacrificing the filtering accuracy of the longer window.

{: .NOTE}
There is a logic that doesn't start the plotting or decision making before the whole buffer is filled when you start the program.

### FIR Filter

### Rectification

### Envelope

### Decision Block



MATLAB magic



1. full wave rectification

ull wave rectification 
In a first step, all negative amplitudes are converted to positive amplitudes; the negative spikes are “moved 
up” to positive or reflected by the baseline (Fig. 37). Besides easier reading, the main effect is that standard 
amplitude parameters like mean, peak/max value and area can be applied to the curve (raw EMG has a 
mean value of zero). 

2. envelope



3. envelope ver2





### Press problems









### Capacitive input

ignore some of the first samples for ADC stabilization

https://devzone.nordicsemi.com/f/nordic-q-a/80796/adc---first-read-is-always-wrong/336435

## Testing

Motor point regions 
Due to increased signal instability some researchers recommend not to place electrodes over motor point regions (area with high density of motor endplates) of the muscle. When using electrode sizes as recommended above, in many cases it cannot be avoided that one electrode comes near a motor point region. Motor points can be detected by low frequency stimulus power generators producing right angled impulses.

Most of the important limb and trunk muscles can be measured by surface electrodes (right side muscles 
in Fig. 26a/26b). Deeper, smaller or overlaid muscles need a fine wire application to be safely or selectively detected. The muscle maps show a selection of muscles that typically have been investigated in 
kinesiological studies. The two yellow dots of the surface muscles indicate the orientation of the electrode 
pair in ratio to the muscle fiber direction (proposals compiled from 1, 4, 10 and SENIAM).



At least one neutral reference electrode per subject needs to be positioned. Typically an electrically unaffected but nearby area is selected, such as joints, bony area, frontal head, processus spinosus, christa iliaca, tibia bone etc

Due to differential amplification against any reference, the latest amplifier technology 
(NORAXON active systems) needs no special area but only a location nearby the first electrode site.





RULES:




## Showcase

WASD Dark Souls for 4 channels?

## Possible improvements

EMG recording should not use any hardware filters (e.g. notch filters), except the amplifier bandpass (10 – 500 Hz) filters that are needed to avoid anti-aliasing effects within 
sampling. 

Especially any type of notch filter (to e.g. cancel out 50 or 60 Hz noise) is not accepted because it destroys too much EMG signal power. Biofeedback units working with heavily preprocessed signals 
should not be used for scientific studies.

Implement filtering in hardware, you can extend SensEdu with another custom shield which will make half of current signal processing unnecessary greatly reducing latency and required computations. In addition, use right leg drive to decrease noise and offset.

## Appendix: data recordings for improvements

## Good study on perfect high pass value
https://www.bu.edu/nmrc/files/2010/06/103.pdf

## Good Resources:
* https://www.nature.com/articles/s41597-022-01484-2
* https://abdominalkey.com/electromyography/
* https://hermanwallace.com/download/The_ABC_of_EMG_by_Peter_Konrad.pdf

## Sources:
* https://youtu.be/_k6QINRcdV4?si=rnil7B-ZlqmRCGSN
* https://youtu.be/ApaPlKPb4ek?si=rHncr0b2XipqN83i

[Byte Size Med]: https://www.youtube.com/channel/UCZghvlgylH3r_CWfA18eFRg
[Action Potential]: (https://en.wikipedia.org/wiki/Action_potential)
[AD8222]: https://www.analog.com/en/products/ad8222.html?doc=ad8222-KGD.pdf
[datasheet]: https://www.analog.com/media/en/technical-documentation/data-sheets/AD8222.pdf
[STM32H747 Reference Manual]: https://www.st.com/resource/en/reference_manual/rm0399-stm32h745755-and-stm32h747757-advanced-armbased-32bit-mcus-stmicroelectronics.pdf

[Arduino GIGA R1 Schematics]: https://docs.arduino.cc/resources/schematics/ABX00063-schematics.pdf

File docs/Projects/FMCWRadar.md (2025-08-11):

---
title: FMCW Radar
layout: default
math: mathjax
parent: Projects
nav_order: 4
---

# FMCW Radar
{: .no_toc .fs-8 .fw-500}
---

{: .WARNING}
This project is currently in its initial development phase and is subject to significant changes, updates, and improvements. The project enables a rudimentary implementation of an FMCW radar and requires two Arduino boards with SensEdu Shields.

The **FMCW Radar Project**{: .text-green-000} utilizes the **SensEdu Shield**{: .text-green-000} to perform **distance measurements**{: .text-green-000} using FMCW radar techniques.
{:.fs-5}

FMCW radars are widely used for short range applications like automotive or drone ranging. These radars have the advantage of providing good spatial resolution while being simple to implement.

## Table of contents
{: .no_toc .text-delta }
1. TOC
{:toc}

## FMCW Radar Principle
{: .text-yellow-300}
This chapter explains the fundamentals of FMCW radars in order to better understand their magic. For more in-depth information, I would recommend [Marshall Bruner's YouTube channel](https://www.youtube.com/@MarshallBrunerRF) — his channel is a gem on the subject! The animated graphs on this doc have been created with the [Manim Community](https://docs.manim.community/en/stable/index.html) python library and are greatly inspired by Marshall Bruner's code.

### Chirp Signal
{: .text-yellow-100}
FMCW radars involves the continuous transmission and reception of a frequency modulated signal also known as chirp. We will call the transmitted signal <span style="color:#57c2da !important">$$T_x$$</span>{: .text-blue-000} and we are using a sawtooth modulation. The sawtooth modulation linearly sweeps a bandwidth $$B$$ over the chirp period $$T_c$$.

The transmitted signal is reflected from a static object and received by the radar. The received signal is called <span style="color:#9c76ab !important">$$R_x$$</span>. Below is a representation of $$T_x$$ and $$R_x$$'s amplitude and frequency over time :

<video autoplay loop muted playsinline>
  <source src="{{site.baseurl}}/assets/videos/TxRx.mp4" type="video/mp4">
</video>
{: .text-center}

$$T_x$$ and $$R_x$$'s Amplitude and Frequency as a Function of Time
{: .text-center}

As we see, $$R_x$$ is exactly the same signal as $$T_x$$ but delayed by $$t_0$$, the time of flight (TOF). We can intuitively establish a relationship between $$t_0$$ and the distance to the object :

<div id="eq1" class="fs-5 text-center">
  $$t_0 = \frac{2d}{c} \tag{1}$$
</div>

where
- $$c = 343 \, \text{m} \cdot \text{s}^{-1}$$ the speed of sound in air $$(T = 293 \, K)$$
- $$d$$ is the distance to the object $$\text{(m)}$$

### Distance
{: .text-yellow-100}
Where pulse radars measure time and TOF to evaluate distance, FMCW radars measure frequencies! The TOF $$t_0$$ cannot be estimated directly since we are sending waves continuously but we have another valuable information : The beat frequency $$f_b$$.

The beat frequency is defined as the frequency equal to the difference between two sinusoids. $$f_b$$ appears in the figure below :

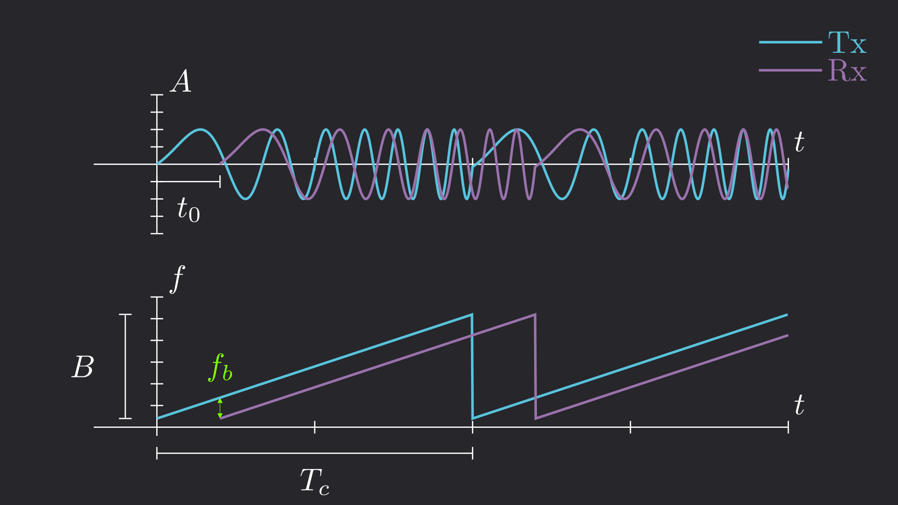
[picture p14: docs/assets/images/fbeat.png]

{: .text-center}

The Beat Frequency $$f_b$$ appears due to the slight delay between $$T_x$$ and $$R_x$$
{: .text-center}

The geometrical approach is the simplest way to understand how to derive the distance from $$f_b$$. Let's define the slope of the chirp $$s$$ being $$s=\frac{B}{T_c}$$. Using the last figure and Eq [(1)](#eq1) we now have the following relationship :

<div id="eq2" class="fs-5 text-center">
  $$f_b = s t_0 = s \frac{2d}{c} \tag{2}$$
</div>

Thus, the distance can easily be derived :

<div id="eq3" class="fs-5 text-center">
  $$\fcolorbox{red}{}{$\displaystyle d = \frac{c f_b}{2s}$} \tag{3}$$
</div>

We know how to compute the distance, that's great! But how do we extract $$f_b$$ ...

### Beat frequency
To extract the beat frequency we need to mix the $$T_x$$ and $$R_x$$. Mixing two signals is essentially multiplying them but it enables us to subtract in the frequency domain.

If we freeze $$T_x$$ and $$R_x$$ at a given time, they're basically two sinusoids at different frequencies. Let's define $$f_T$$ and $$f_R$$ the instantaneous frequencies of our two signals where $$f_T>f_R$$ (the phase of the signals is not relevant here). We also define $$y_{mix}$$ the mixed signal.

At a given time, $$y_{mix}$$ is expressed as

<div id="eq4" class="fs-5 text-center">
  $$ 
  y_{mix} = T_x \cdot R_x = \sin(2 \pi f_{T} t) \cdot \sin(2 \pi f_{R} t) \\
  = \frac{1}{2}\big[\cos\big(2 \pi \textcolor{#7FFF00}{\underbrace{(f_T-f_R)}_{f_b}} t\big) + \cos\big(2 \pi \textcolor{#008000}{\underbrace{(f_{T}+f_{R})}_{\text{HF component}}} t\big)\big] \tag{4}
  $$
</div>

The mixing operation produces a signal which is the sum of two sinusoids :
- One at the frequency $$f_{T}-f_{R}$$
- One at the frequency $$f_{T}+f_{R}$$

The high frequency component HF at $$f_{T}+f_{R}$$ can easily be removed with a low pass filter. The remaining signal is a simple sinudoid at the beat frequency $$f_b=f_{T}-f_{R}$$. Below is a representation of the mixing signal operation :

<video autoplay loop muted playsinline>
  <source src="{{site.baseurl}}/assets/videos/Mixing.mp4" type="video/mp4">
</video>
{: .text-center}

$$y_{mix}$$ is the product of $$T_x$$ and $$R_x$$
{: .text-center}

### Distance Resolution & Max Range 

Distance resolution and max range are two critical parameters regarding radar performance. Distance resolution defines the smallest distance between two objects that the radar can detect as distinct targets. The distance resolution $$\Delta d$$ is defined by

<div id="eq5" class="fs-5 text-center">
  $$\fcolorbox{red}{}{$\displaystyle \Delta d = \frac{c}{2B}$} \tag{5}$$
</div>

where

- $$c$$ is the speed of sound $$\text{(m} \cdot \text{s}^{-1})$$

- $$B$$ is the bandwidth of the chirp  $$\text{(Hz)}$$

{: .IMPORTANT}
Distance resolution is only dependent on the radar's bandwidth !

For ultrasonic FMCW radars, the maximum range $$d_{max}$$ is heavily limited by $$T_c$$. The maximum range $$d_{max}$$ is defined by

<div id="eq6" class="fs-5 text-center">
  $$\fcolorbox{red}{}{$\displaystyle d_{\text{max}} = c \frac{T_c}{2}$} \tag{6}$$
</div>

where

- $$c$$ is the speed of sound $$\text{(m} \cdot \text{s}^{-1})$$

- $$T_c$$ is the period of the chirp  $$\text{(s)}$$

{: .IMPORTANT}
For ultrasonic FMCW radars, the max range bottleneck is $$T_c$$. For regular FMCW radars, it's usually the ADC sampling frequency.

## Radar Design
{: .text-yellow-300}

The following block diagram illustrates the architecture of the FMCW radar :

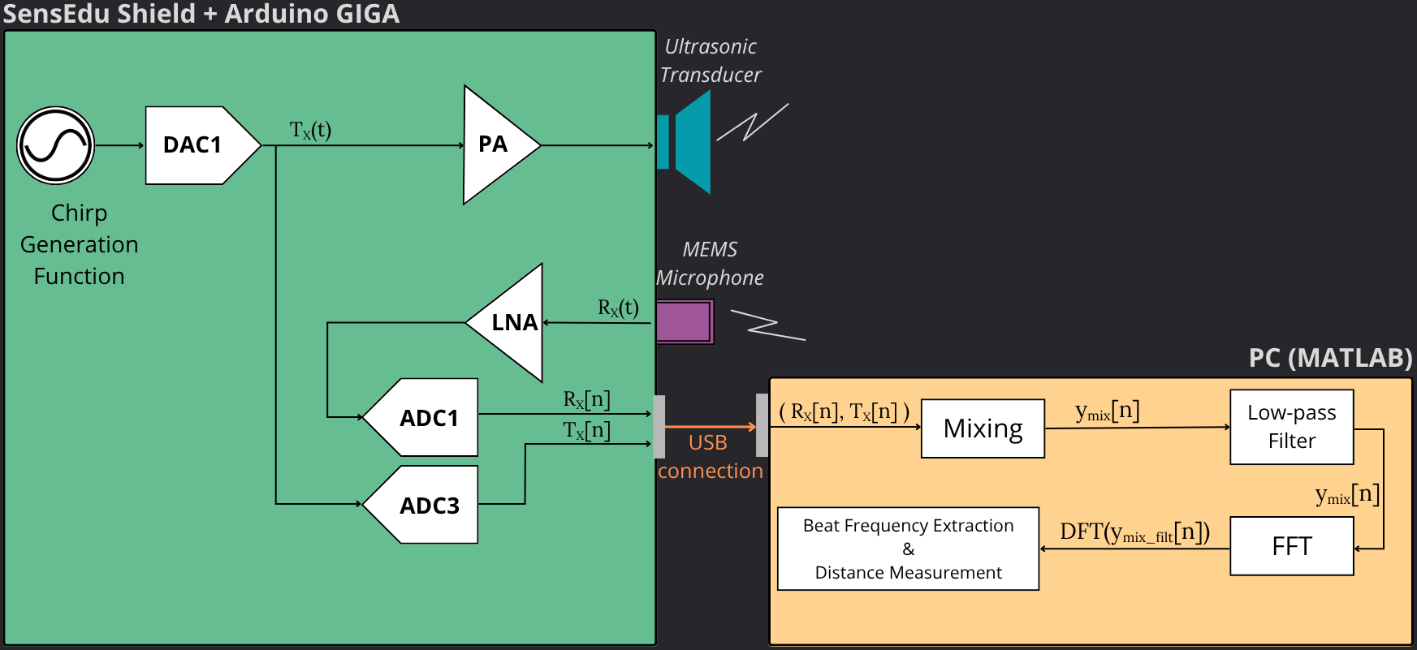
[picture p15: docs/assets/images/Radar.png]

{: .text-center}

FMCW Radar Block Diagram
{: .text-center}

The chirp signal Tx is generated and converted to an analog signal with the DAC. Tx is then doubled and follows 2 paths :

- Tx is amplified and sent to the ultrasonic transducer
- Tx is sent to ADC3 by using a jump wire between the DAC pin and the receiver ADC3 pin (A8).

The MEMS microphone receives a signal Rx which is amplified with a low noise amplifier (LNA) and goes through ADC1. The digital Tx and Rx signals are both sent to MATLAB.

The following signal processing is performed in MATLAB to measure the distance between the two shields :

- Compute mixing operation between Tx and Rx
- Compute FFT of mixed signal $$y_{mix}$$
- Low-pass filter $$y_{mix}$$
- Extract beat frequency and compute distance 

## Code Implementation
{: .text-yellow-300}

{: .IMPORTANT}
Make sure to wire the DAC output to ADC3 (analog pin `A8`).

### Sending the ADC data and receiving in MATLAB
{: .text-yellow-100}

- ADC3 receives the DAC data
- ADC1 receives the microphone #3 data

A size header `adc_byte_length`  is sent to MATLAB to indicate the size of each ADC frame in bytes. Since ADCs are 16-bit, each data is coded with 2 bytes. The data from both ADCs is sent to MATLAB using the `serial_send_array` function.

```c
// Send ADC data (16-bit values, continuously)
    uint32_t adc_byte_length = mic_data_size * 2; // ADC data size in bytes
    Serial.write((uint8_t*)&adc_byte_length, sizeof(adc_byte_length));  // Send size header
    serial_send_array((const uint8_t*)adc_dac_data, adc_byte_length);       // Transmit ADC3 data
    serial_send_array((const uint8_t*)adc_mic_data, adc_byte_length);       // Transmit ADC1 data (Mic3 data)
```

An important variable is `mic_data_size` which must be a multiple of 32 because `serial_send_array` sends data by chunks of 32-bytes. `mic_data_size` will also define the amount of samples used for the plots in MATLAB.

The bigger the value of `mic_data_size`, the more latency when you run the MATLAB distance measurement script but the more signal will be displayed on the plots.

```c
// Retrieve size header for ADC data
    adc_byte_length = read_total_length(arduino);      // Total length of ADC data in bytes
    ADC_DATA_LENGTH = adc_byte_length / 2;             // Total number of ADC samples

    // Retrieve DAC to ADC data
    adc3_data = read_data(arduino, ADC_DATA_LENGTH);

    // Retrieve Mic ADC data
    adc1_data = read_data(arduino, ADC_DATA_LENGTH); 
```

### Data processing in MATLAB & Distance computation
{: .text-yellow-100}

After sending the data to MATLAB, the data can be processed and the distance is eventually computed. It is worth noting that a high-pass FIR filter has also been applied to the mixed signal in MATLAB. This is to attenuate low frequencies (15 Hz to 46 Hz) in the spectrum coming from the transducer's signal directly received by the microphone. These frequencies don't correspond to an object's reflection and thus need to be mitigated. This is important to mitigate the right amount of reflections

Here are the different steps in order to compute the distance in MATLAB.

**Step 1**{: .text-blue-000} : High pass filter Tx (`adc3_data`) and Rx (`adc1_data`) to clean up the signals

```c
    adc3_data_filt = highpass(adc3_data, 30000, SAMPLING_RATE);
    adc1_data_filt = highpass(adc1_data, 30000, SAMPLING_RATE);
```

**Step 2**{: .text-blue-000} : Mix Tx and Rx using sample-by-sample multiplication

```c
    mixed_signal = adc3_data_filt .* adc1_data_filt;
```

**Step 3**{: .text-blue-000} : Low-pass filter the mixed signal at 5 kHz to remove the unwanted high frequency component

```c
    mixed_signal_filt = lowpass(mixed_signal, 5000, SAMPLING_RATE);
```

**Step 4**{: .text-blue-000} : Compute the power spectrum density (PSD) of the mixed filtered signal

```c
    [p_mix_filt, f_mix_filt] = pspectrum(mixed_signal_filt, SAMPLING_RATE);
```

**Step 5**{: .text-blue-000} : Extract the beat frequency from the PSD of the mixed filtered signal

```c
    [p_fbeat,fbeat] = findpeaks(p_mix_filt,f_mix_filt,NPeaks=1,SortStr="descend");
```

**Step 6**{: .text-blue-000} : Compute the distance

```c
    d = (fbeat * Tc * c) / (2*(f_end - f_start));
```

{: .IMPORTANT}
Make sure the parameters in MATLAB match the parameters of the chirp you are sending (f_start, f_end, Tc, etc...).

After running the MATLAB code, you should see the following display. This example is with an object placed at 50 cm from the board and using the following radar parameters :
- f_start = 30.5 kHz
- f_end = 35.5 kHz
- Tc = 40 ms

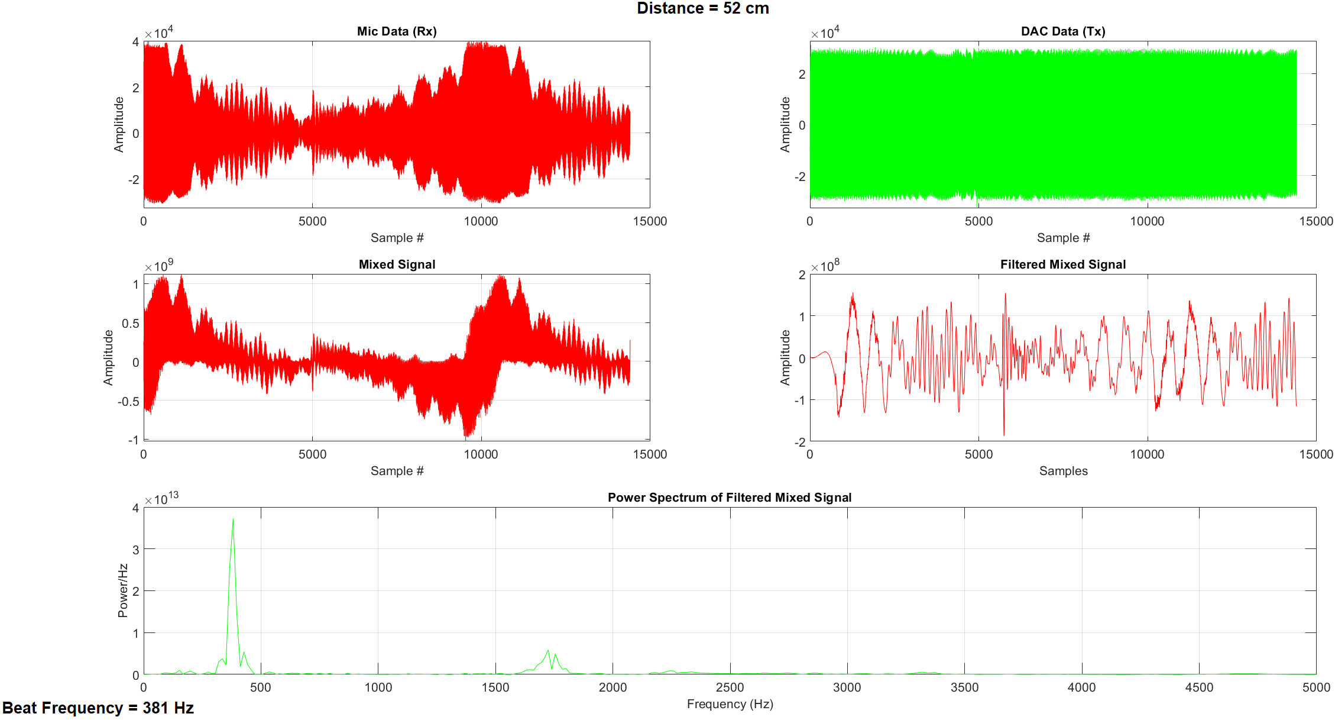
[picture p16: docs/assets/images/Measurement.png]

{: .text-center}

Measurement display in MATLAB
{: .text-center}

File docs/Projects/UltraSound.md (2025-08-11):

---
title: Ultrasonic Ranging
layout: default
math: mathjax
parent: Projects
nav_order: 1
---

# Ultrasonic Ranging
{: .fs-8 .fw-500}
---

Using the latest SensEdu Shield on an Arduino Giga R1 platform, we want to get the distance measurements for all 4 MEMS microphones. 
In this project, we use SensEdu Library and DMA approach for fast and efficient data acquisition. This can represent a prerequisitie 
for other projects for further processing the distance measurements. The data from the microphones is processed and sent via Serial Communication on a PC. 

The project is divided into 2 main parts: 
* **Arduino GIGA R1 WiFi with SensEdu Shield**: Data acquisition and sending the measurements data
* **PC with MATLAB**: Starting the data acquisition and receiving the measurements data

## Serial Communication 

The communication is done using a Half Duplex method and UART communication protocol - each sender and receiver can transmit the data but not at the same time. This is needed since the data acqusition is started only after the PC (sender) sends the starting signal to the board. After the starting signal, data acquisition and data sending is performed for a predefined amount of time. 

## Data Acquisition and Sending the Data

The following data acquisition flow chart explains the algorithm. 

Since the microcontroller is ecquiped with three ADCs and we use four microphones, we use two ADCs - ADC1 and ADC2 accessing through two channels all four microphones. The ADC sampling rate is set to 250 kHz. 

{: .IMPORTANT }
The exact sampling rate is very important for exact measurement acquisition. Make sure it matches throughout the code. 

### About the Sampling Rate

In this project, the ADC sampling rate is set to 250 kHz.  

#### How to change ADC Sampling Rate?
Changing the ADC sampling rate correctly requires the following steps: 
1. In .ino script - set "**.sampling_freq**" field of SensEdu_ADC_Settings structure 
2. In .ino script - set "**ACTUAL_SAMPLING_RATE**" macro to the same value
3. In "**generateDAC.m**" - set "**fs**" variable to match the wanted sampling frequency and generate a new LUT
4. Copy the new LUT to the "**SineLUT.h**" file

{: .NOTE }
Currently, the library *does not* support different sampling rates for different ADCs since all the ADCs use the same timer. 

As for the DAC sampling rate, it is caluclated as frequency of the wave that is sent - in our case 32 kHz sine wave multiplied by the number of samples that the wave has for one cycle. 

To generate the measurements, first burst sine signal with 32 kHz frequency is sent through DAC1. The sine wave is stored in a lookup table (LUT) as an uint16_t array. 

After the burst is sent, ADC starts to collect the data microphones are receiving. The raw data is represented with 16bit values corresponding to the changes in pressure received by microphones. 

### How is the distance computed

The main difference between the audible sound and ultrasound is the frequency range. Other characteristics are the same. Therefore, we know that the sound travels through the air with constant speed of about 343 m/s. 
Since the speed is constant, the distance can be calculated using the simple formula for constant motion:

$$
\begin{equation}
v = \frac{d}{t}
\label{eq:speed}
\end{equation}
$$

Therefore, the time is what we need to compute the distance. The time is computed as a time-of-flight (TOF) of the reflected DAC signal from the object. To compute the TOF, the cross-correlation method is used. 
Cross-correlation method essentially compares two signals and detects the point at which they have the most similarity.
In this case, the cross-correlation is performed between the output wave of the DAC and input wave of the ADC. 

{: .NOTE}
For correct cross-correlation, DAC output signal has to have the same sampling rate as the ADC signal. Therefore, this signal is 
additionally computed using the provided MATLAB script *"dac_wave_gen.m"*. Make sure to adjust the sampling rate in the script to the real sampling rate of 
the ADC previously computed! 

There are two intersteps before the cross-correlation is performed: 

#### Rescaling the ADC signal

The ADC signal has values in range [0, 65535]. Therefore, we first rescale the signal to have the range [-1, 1] with each sample being 
a 4-byte float value using the *"rescale_adc_wave"* function. 

{: .NOTE}
Because of the way multi-channel ADC signals are stored in memory using SensEdu library, the channel number has to be passed to the function. 

#### Filtering the rescaled signal
Since we are working with microphones with frequency range between 20 Hz and 100 kHz, they are very sensitive to audible sound as well. 
This is undesired in our case because we want to have a signal that is around 32 kHz in order to get good results. Therefore, a Finite
Impulse Response (FIR) bandpass filter is applied to the previously resacaled ADC signal using the *"filter_32kHz_wave"* function. 

Finally, the cross-correlation method is performed on the filtered signal and ouput signal. The result of the cross-correlation is number of lag 
samples between the two signals. Then, the distance is computed as: 

$$
\begin{equation}
d = \frac{(lag\_samples \cdot sample\_time)}{sampling\_rate \cdot 2}
\end{equation}
$$

Two modes are possible for sending the data depending on the value of preprocessor macro *"XCORR_DEBUG"*. Setting this value to *true*
sends raw-, rescaled-, and filtered data with distance measurements to the PC. Otherwise, only the distance measurements will be sent to the PC.  

{: .NOTE}
For faster measurements, cross-correlation is performed directly on the microcontroller. However, if the time-efficiency is not
a requirement, setting preprocessor macro *"LOCAL_XCORR"* to *false* will directly send raw ADC data to the PC. 

## Receiving the Data

Data is received on the PC using MATLAB script *plot_microphones_data.m*. The function *read_mcu_xcorr.m* reads the distance data, and the 
function *read_mcu_xcorr_details.m* reads raw-, rescaled-, and filtered data. 

Since we are using serial communication, the data is received one bit at a time. To start receiving the data from the microcontroller, the PC initiates the communication by sending the starting byte. 

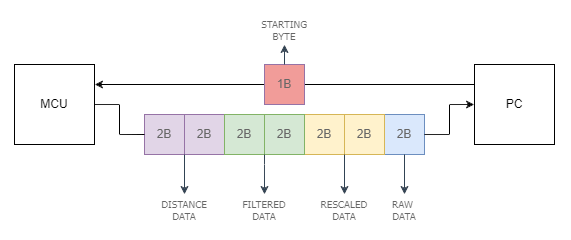
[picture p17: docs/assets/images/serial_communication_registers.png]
Serial communication between the mcu and the pc

{: .text-center}

This diagram depicts one iteration of PC receiving the data. This continues for number of iterations that are specified in the MATLAB script. Then, the data is plotted for visualization.

{: .IMPORTANT}
Make sure that *PLOT_DETAILED_DATA* in MATLAB matches the value of *XCORR_DETAILS*, as well as to set *DATA_LENGTH* in MATLAB to be the same as *STORE_BUF_SIZE* macro. Make sure to choose the correct *ARDUINO_PORT* to match the real one.

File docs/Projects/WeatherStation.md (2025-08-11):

---
title: Weather Station
layout: default
math: mathjax
parent: Projects
nav_order: 6
---

# Weather Station
{: .no_toc .fs-8 .fw-500}
---

{: .WARNING}
This project is currently in its initial development phase and is subject to significant changes, updates, and improvements.

- TOC
{:toc}

## Introduction

Introduction

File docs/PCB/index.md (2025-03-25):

---
title: PCB
layout: default
nav_order: 3
permalink: /pcb/
---

# PCB Design
{: .fs-8 .fw-500 .no_toc}
---

SensEdu focuses on the design and development of a Printed Circuit Board (PCB) tailored for the Arduino GIGA R1. The objective is to create a versatile and efficient platform capable of accommodating a wide range of ultrasound applications, ensuring optimal performance and ease of integration.
{: .fw-500}

- TOC
{:toc}

## Overview
This shield extends the Arduino Giga’s capabilities for ultrasound applications, including:

- 4-channel MEMS microphone array ([Infineon IM73A135V01XTSA1](https://www.infineon.com/dgdl/Infineon-IM73A135-DataSheet-v01_00-EN.pdf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)) for signal acquisition.
- Ultrasound transmitters ([Prowave 328ST160](https://www.farnell.com/datasheets/4413630.pdf)) for generating 32.8 kHz signals.
- Multi-voltage LDOs for stable digital power.
- [DPS310 barometric sensor](https://www.infineon.com/dgdl/Infineon-DPS310-DataSheet-v01_02-EN.pdf?fileId=5546d462576f34750157750826c42242) for environmental compensation.
- Flexible input/output routing via jumpers.

## Software Used

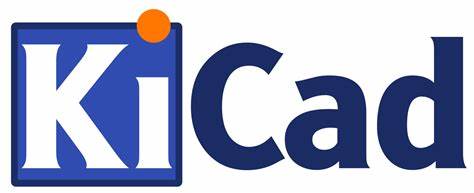
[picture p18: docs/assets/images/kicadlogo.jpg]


The PCB for this project was designed using [KiCad](https://kicad.org/), an open-source software suite for electronic design automation (EDA). KiCad offers a comprehensive set of tools for schematic capture, PCB layout, and 3D visualization.

- **Version**: 7
- **Features**:
  - **Schematic Capture**: Design complex circuit diagrams with ease.
  - **PCB Layout**: Powerful tools for multilayer PCB design.
  - **3D Viewer**: Visualize your board in 3D to check component placement and fit.

### Installation and Setup of KiCad
{: .no_toc}
1. **Download KiCad**:
   - Visit the [KiCad download page](https://kicad.org/download/).
   - Select your operating system (Windows, macOS, Linux) and download the installer.

2. **Install KiCad**:
   - **Windows**:
     - Run the downloaded installer.
     - Follow the on-screen instructions to complete the installation.
     - Optionally, install additional libraries and templates.
   - **macOS**:
     - Open the downloaded `.dmg` file.
     - Drag the KiCad application to the Applications folder.
   - **Linux**:
     - Follow the instructions on the KiCad download page for your specific Linux distribution.

3. **Initial Configuration**:
   - Launch KiCad.
   - Go to `Preferences > Configure Paths` to set up the environment variables.
   - Add any custom libraries or footprints if needed.

4. **Open the `SensEdu` Project**:
    - Download the `SensEdu` project files from the repository.
    - Place the project files in a desired directory on your computer.
    - Open KiCad and click on `File > Open Project`.
    - Navigate to the directory where the `SensEdu` project files are located and select the project file `.kicad_pro`

## KiCad Files  
- **Schematic**: <a href="{{site.baseurl}}/assets/pdf/Schematics.pdf" target="_blank">Download the PDF</a>

### PCB Layout
### 4-Layer Stackup
1. **Top Layer**: Signal routing for components.
2. **Layer 2**: Solid ground plane (noise reduction).
3. **Layer 3**: Power planes (3.3V, 2.5V, 1.25V).
4. **Bottom Layer**: Signal routing for for components.

**Front side**
{: .mb-1}

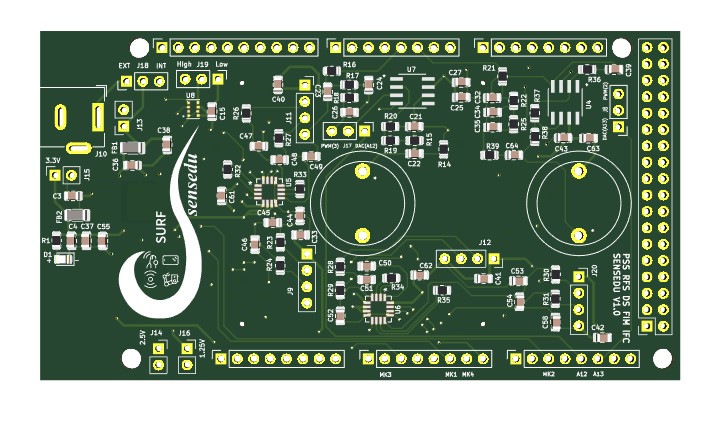
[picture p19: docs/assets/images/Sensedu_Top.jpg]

{: .text-center .mt-0}

**Back side**
{: .mb-1}

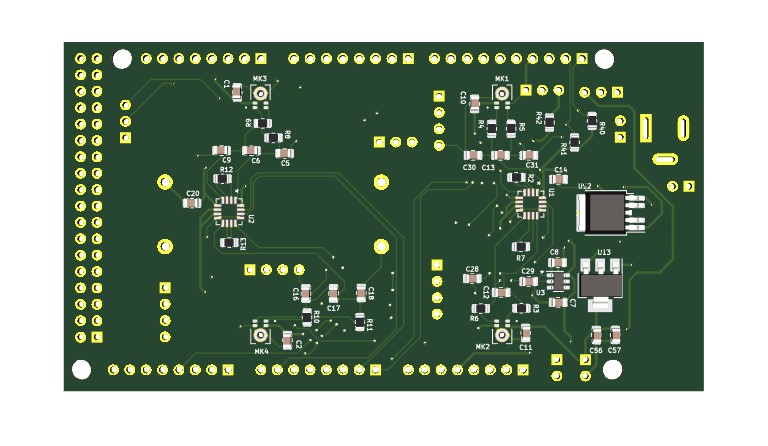
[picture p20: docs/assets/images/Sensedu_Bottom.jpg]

{: .text-center .mt-0}

## Hardware Design

### Power Supply
#### Key Components:
{: .no_toc}
- **Primary LDO ([Infineon TLS850C2TEV33ATMA1](https://www.infineon.com/dgdl/Infineon-TLS850C2TE%20V33-DataSheet-v01_00-EN.pdf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))**:
  - Converts 5V (Arduino) or DC barrel jack (7–12V) to 3.3V for the shield.
  - Selected for low noise (22 µV RMS) and high PSRR (70 dB) to stabilize analog circuits.

- **Secondary LDOs**:
  - **[NCP1117-2.5_SOT223](https://www.onsemi.com/download/data-sheet/pdf/ncp1117-d.pdf)**: Generates 2.5V for MEMS microphones.
  - **[LT1790ACS6-1.25](https://www.analog.com/media/en/technical-documentation/data-sheets/1790fc.pdf)**: Provides 1.25V reference for amplifier outputs.

#### Power Paths:
{: .no_toc}
- Barrel Jack (J10) → Jumper J18 → TLS850 LDO → 3.3V rail.
- Arduino 5V → Jumper J18 → TLS850 LDO → 3.3V rail.

#### Indicators:
{: .no_toc}
- Green LED lights when 3.3V is active.

### Sensors
- **MEMS Microphones ([Infineon IM73A135V01XTSA1](https://www.infineon.com/dgdl/Infineon-IM73A135-DataSheet-v01_00-EN.pdf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))**

	The Infineon IM73A135V01XTSA1 is a high-performance MEMS Analog microphone designed for precise sound capture. It is particularly suitable for ultrasound applications due to its high Signal-to-Noise Ratio (SNR) and low Total Harmonic Distortion (THD).

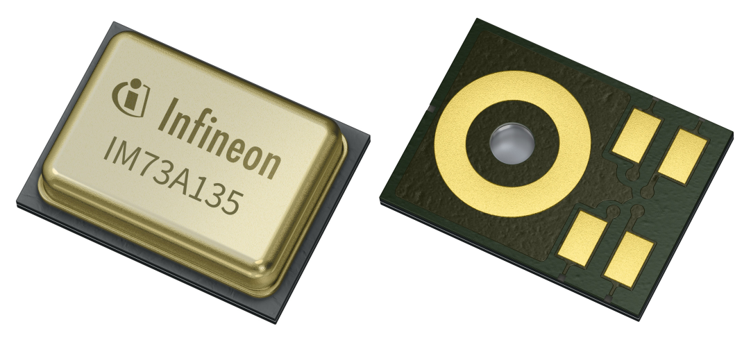
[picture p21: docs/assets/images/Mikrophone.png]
	
  {: .text-left}

- **Quantity**: 4
- **Key Features**:
  - **SNR**: 73 dB, which is excellent for capturing low-level ultrasound signals with high fidelity.
  - **Frequency Response**: Wide and flat frequency response suitable for ultrasound frequencies.
  - **Sensitivity**: -38 dBV/Pa, ensuring that even weak ultrasound signals can be detected.
  - **Low Power Consumption**: Efficient power usage, critical for battery-operated or low-power applications.
- **Power Supply**: 
  - 2.5V supply from the NCP1117 LDO.
- **Outputs Routed to Arduino ADC Pins**:
  - MK1 → A5
  - MK2 → A10
  - MK3 → A1
  - MK4 → A6

- **Barometric Pressure Sensor ([Infineon DPS310](https://www.infineon.com/dgdl/Infineon-DPS310-DataSheet-v01_02-EN.pdf?fileId=5546d462576f34750157750826c42242))**

	The DPS310 is a high-precision barometric pressure sensor designed by Infineon. It measures both pressure and temperature, providing essential environmental data that can be used to compensate for variations in ultrasound propagation due to changes in atmospheric conditions.

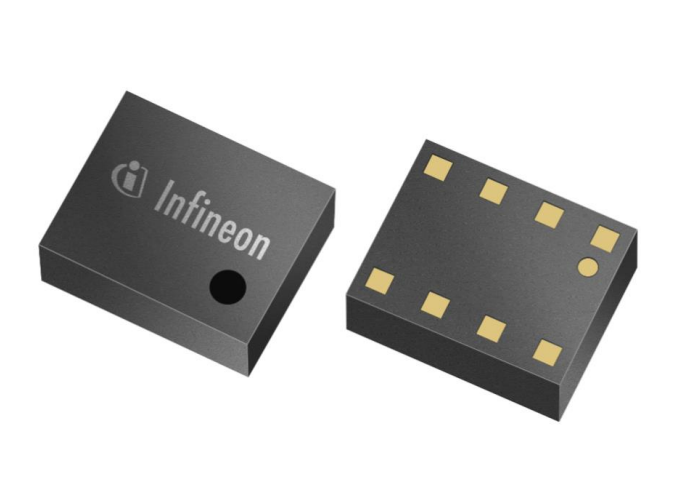
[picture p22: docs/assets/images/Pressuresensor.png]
	
	{: .text-left}

- **Interface**: I2C (SCL1/SDA1)
- **Key Features**:
  - **Pressure Range**: 300 to 1200 hPa, suitable for most environmental conditions.
  - **Temperature Range**: -40 to 85°C, allowing for robust operation in various environments.
  - **High Accuracy**: Pressure accuracy of ±1 hPa and temperature accuracy of ±0.5°C, ensuring precise environmental compensation.
  - **Low Power Consumption**: Ideal for continuous monitoring without significant power drain.
- **Usage**: 
  - The DPS310 is used to measure atmospheric pressure and temperature, which can then be used to adjust the ultrasound measurements for more accurate distance and velocity calculations.

### Amplifiers
- **Instrumentation Amplifier ([AD8426ACPZ-R7](https://www.analog.com/media/en/technical-documentation/data-sheets/ad8426.pdf))**:
  
	The AD8426ACPZ-R7 is a high-performance instrumentation amplifier from Analog Devices. It is designed for accurate, low-noise amplification of small differential signals, making it ideal for amplifying the weak signals from the MEMS microphones in ultrasound applications.

- **Key Features**:
  - **Low Noise**: 1 nV/√Hz noise density, ensuring minimal introduction of noise into the signal.
  - **High Common-Mode Rejection Ratio (CMRR)**: Ensures that noise from the power supply or other sources is minimized.
  - **Single-Supply Operation**: 3.3V supply voltage, compatible with the overall system design.
  - **Configurable Gain**: Gain can be set using external resistors, with a typical configuration providing a gain of 50 (using a 1kΩ resistor).
- **Usage in Design**:
  - **Microphone Signal Amplification**: The AD8426 amplifiers are used to boost the low-level signals from the MEMS microphones (IM73A135V01XTSA1) to levels suitable for digital processing.
  - **Configuration**: 4x AD8426 amplifiers provide four channels of amplification, each with a gain of 50. In which 2 are  for Infineon IM73A135V01XTSA1 microphones and 2 for external sources.
  - **Apmlifier for external signals**:  ***J9/J11/J12/J20***: 4-pin headers for connecting external microphones or other signal sources.
    - Pin 1: 2.5V (mic supply)
    - Pin 2: Amplifier input -
    - Pin 3: Amplifier input +
    - Pin 4: GND

### Ultrasound Transmitters

- **Speakers ([Prowave 328ST160](https://www.farnell.com/datasheets/4413630.pdf))**: 
   
	The Prowave 328ST160 is an ultrasound speaker designed specifically for emitting high-frequency sound waves. With a resonance frequency of 32.8 kHz, it is ideal for generating ultrasound signals that can be used in various applications such as distance measurement and object detection.

- **Key Features**:
  - **Resonance Frequency**: 32.8 kHz, which is optimal for many ultrasound applications.
  - **High Sound Pressure Level (SPL)**: Ensures strong and consistent ultrasound signal transmission.
  - **Directional Beam Pattern**: Focuses the ultrasound waves, improving accuracy in detecting reflections from objects.
  - **Durability**: Designed to withstand environmental factors, making it suitable for both indoor and outdoor applications.
- **Integration in Design**:
  - **Driving Circuit**: The ultrasound speakers are driven by the ADA4891-1ARZ-R7 operational amplifier, which provides the necessary gain and power to achieve optimal performance.
  - **2x Speakers (LS1&LS2)**
  - **Signal Input Options**: 
    - **Analog Waveforms**: Provided through Arduino DAC pins (A12 and A13).
    - **PWM Signals**: Filtered through an RC network (4.7kΩ resistor and 1nF capacitor → cutoff ~34 kHz) to achieve a smooth signal, selectable via jumpers J8 and J17.
  - **Power Supply**: Operates with a single 3.3V supply, ensuring compatibility with the rest of the system.

- **Operational Amplifier ([ADA4891-1ARZ-R7](https://www.analog.com/media/en/technical-documentation/data-sheets/ADA4891-1_4891-2_4891-3_4891-4.PDF))**:

  	The ADA4891-1ARZ-R7 is a high-speed, low-noise operational amplifier from Analog Devices. It is designed for applications requiring fast and precise signal amplification, making it suitable for driving the ultrasound transmitters (Prowave 328ST160).

- **Key Features**:
  - **High Slew Rate**: Ensures rapid response to input signal changes, critical for generating clean ultrasound signals.
  - **Low Noise**: Low input noise density, providing a clean amplification of the input signal.
  - **Single-Supply Operation**: 3.3V supply voltage, compatible with the overall system design.
  - **Configurable Gain**: Gain can be set using external feedback resistors, with the current configuration providing a gain of 4 (using a 3kΩ feedback resistor and a 1kΩ resistor to ground).
- **Usage in Design**:
  - **Driving Ultrasound Transmitters**: The ADA4891 amplifiers are used to drive the Prowave 328ST160 speakers, providing the necessary power and precision to generate effective ultrasound signals.
  - **Integration**: Operates with a single 3.3V supply, ensuring compatibility with the rest of the system.

### Design Choices
- Ground plane isolates sensitive analog paths.
- Short traces for amplifier inputs to minimize noise.

## Connections & Pinouts
### Key Headers/Jumpers:
{: .no_toc}

| Component | Function |
|:---|:---|
| J18 | Selects power source (Arduino 5V or barrel jack).  |
| J8/J17 | Route PWM/DAC signals to transmitters. |
| J13 | Barrel jack input (7–12V). |
| J15/J14/J16 | Test points for 3.3V, 2.5V, 1.25V. |

[link1]: https://docs.github.com/en/get-started/writing-on-github/getting-started-with-writing-and-formatting-on-github/basic-writing-and-formatting-syntax
[link2]: https://just-the-docs.com/
[Infineon IM73A135V01XTSA1]: https://www.infineon.com/dgdl/Infineon-IM73A135-DataSheet-v01_00-EN.pdf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

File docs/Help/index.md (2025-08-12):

---
title: Help
layout: default
nav_order: 6
permalink: /help/
---

# Getting Help
{: .fs-8 .fw-500 .no_toc}
---

Please start by trying to resolve the issue on your own:
* Read the [Getting Started]({% link Getting Started/index.md %}) section
* Use the Search bar on this wiki to find information related to your problem
* Browse the [Frequently Asked Questions (FAQs)]({% link Help/index.md%}#faqs) below
* ~~ChatGPT~~ Google your issue

If you have tried the above and are still stuck, it is a good time to ask for help.

## Contact us

The best way to contact us is via [Discussion]. If you want to keep things private, you can contact [me] or other contributors from the SensEdu team.

When asking for help:
* Avoid vague questions like "it doesn't work"
* Try to give as much details as possible. Tell us what you have tried, required steps to recreate your issue
* Provide details about your hardware setup
* Add screenshots

Your details will help us greatly to answer your question!

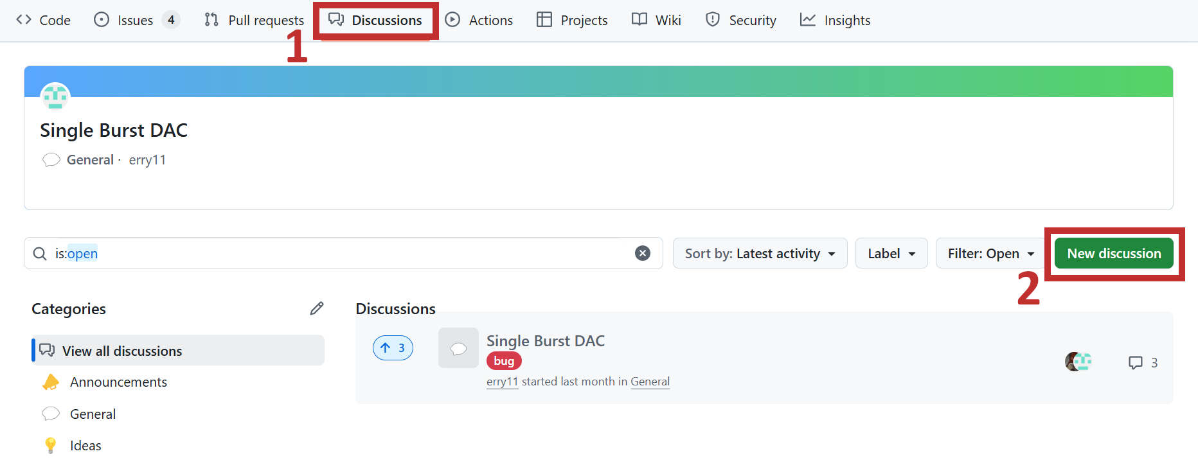
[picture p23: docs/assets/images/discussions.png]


## FAQs

#### How to get the shield?
{: .no_toc}
Please send us an e-mail: <a href="mailto:Vladyslav.Sorokin@infineon.com">Vladyslav.Sorokin@infineon.com</a>.

#### How to participate in the project?
{: .no_toc}
Start with the [Contributing Guide]({%link Contributing/index.md %}) and create a [Discussion] on GitHub, we would discuss your ideas and help you get started!

#### No signal in ultrasonic ranging examples
{: .no_toc}
You probably forgot to enable the speaker with 2-pin jumper on SensEdu, follow Step #1 from [Getting Started]({% link Getting Started/index.md %}) section.

[Discussion]: https://github.com/ShiegeChan/SensEdu/discussions
[me]: https://github.com/vladysor

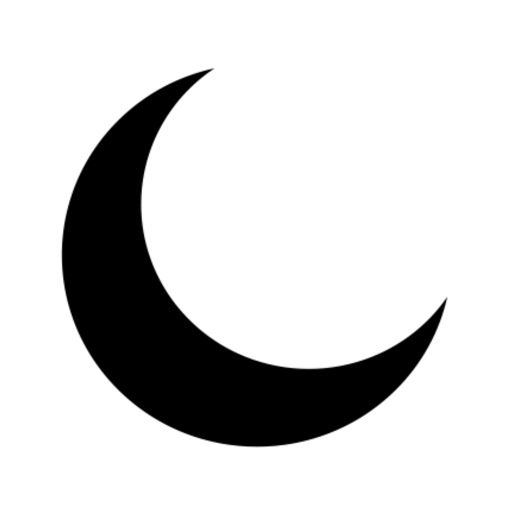
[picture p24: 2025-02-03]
docs/assets/images/moon.png

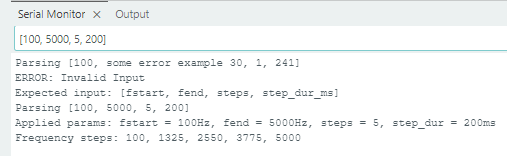
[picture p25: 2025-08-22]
docs/assets/images/PWM_FreqSweepInput.png

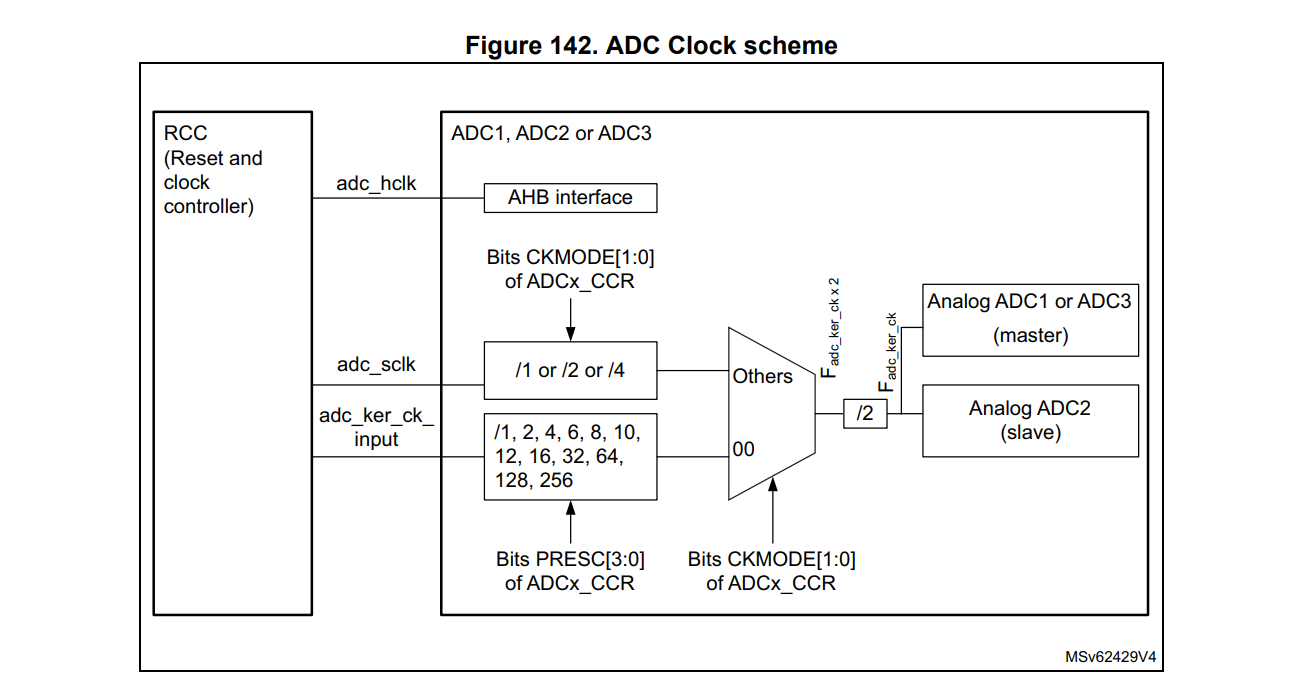
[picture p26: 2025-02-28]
docs/assets/images/ADC_Clock.png

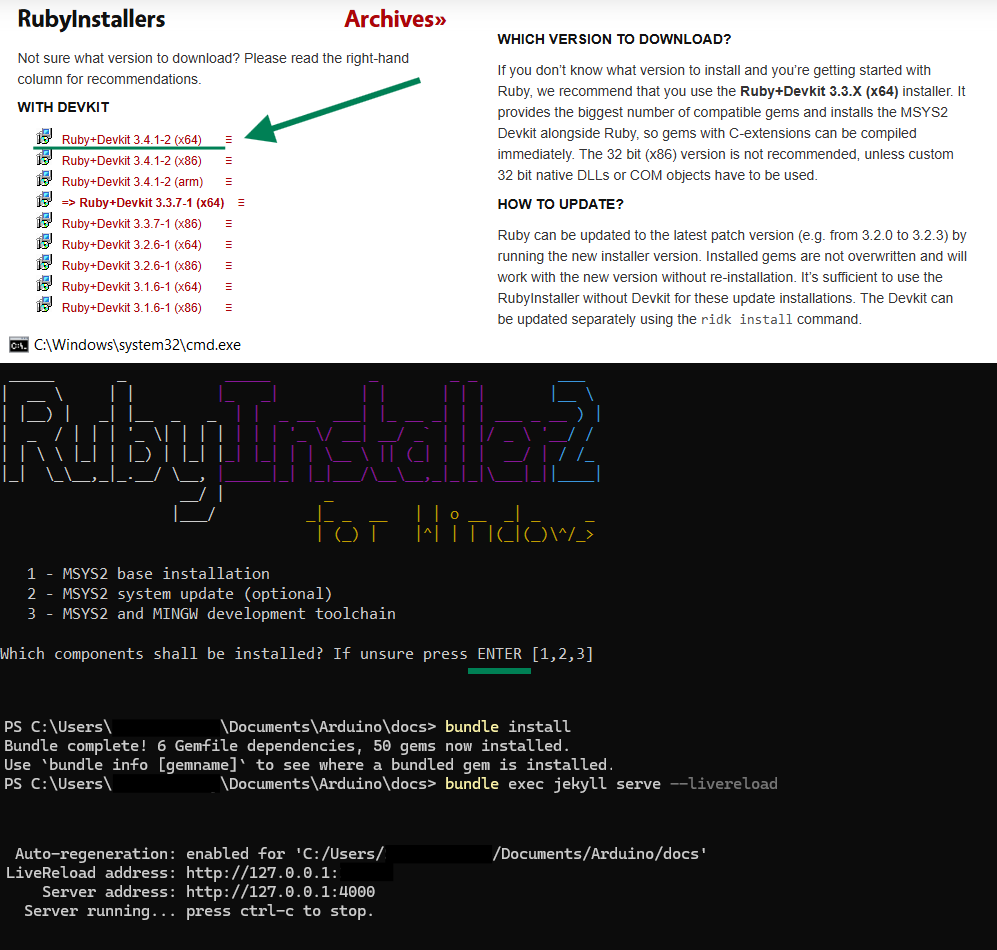
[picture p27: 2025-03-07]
docs/assets/images/readme_docs.png

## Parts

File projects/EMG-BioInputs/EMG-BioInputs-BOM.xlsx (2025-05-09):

Name | Product Code | Quantity | 1x Price | Total | Link | Notes:
SENSOR CABLE - ELECTRODE PADS | 12970 | 12 | €8.44 | €101.28 | https://www.digikey.at/de/products/detail/sparkfun-electronics/12970/6833933
гелевые пады |  |  |  | €0.00
CONN HEADER R/A 4POS 2.54MM | 0901210124 | 25 | €0.51 | €12.83 | https://www.digikey.at/en/products/detail/molex/0901210124/760813 | socket for reference: | https://www.farnell.com/datasheets/2925583.pdf?_gl=1*4kzof5*_gcl_au*MjAyMzgyNzc1OC4xNzQ2NzAzOTEy
3.5mm F PCB Headphone Jack | 35RASMT2BHNTRX | 25 | €1.52 | €37.91 | https://www.digikey.at/en/products/detail/switchcraft-inc/35RASMT2BHNTRX/1291178 | clear length info: | https://eu.mouser.com/ProductDetail/Molex/90121-0124?qs=PvP5v7EimskrWnL4DJlIPg%3D%3D
 |  |  |  | €152.01

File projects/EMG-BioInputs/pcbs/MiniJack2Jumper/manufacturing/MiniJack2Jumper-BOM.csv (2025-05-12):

Reference | Value | Qty | DigiKey Link | DigiKey Part Number | Datasheet
J2 | 901210124 | 1 | https://www.digikey.at/en/products/detail/molex/0901210124/760813 | 23-0901210124-ND | https://www.molex.com/pdm_docs/sd/901210124_sd.pdf
J1 | 35RASMT2BHNTRX | 1 | https://www.digikey.at/en/products/detail/switchcraft-inc/35RASMT2BHNTRX/1291178 | SC1489-1-ND | https://www.switchcraft.com/assets/1/24/35rasmt2bhntrx_cd.pdf?4698

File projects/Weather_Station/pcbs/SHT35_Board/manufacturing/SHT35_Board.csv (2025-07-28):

Reference | Qty | Value | DNP | Exclude from BOM | Exclude from Board | Footprint | Datasheet
C1 | 1 | 100n |  |  |  | Capacitor_SMD:C_0805_2012Metric_Pad1.18x1.45mm_HandSolder | ~
J1 | 1 | Conn_01x03 |  |  |  | Connector_PinHeader_2.54mm:PinHeader_1x03_P2.54mm_Vertical | ~
J2 | 1 | Conn_01x02 |  |  |  | Connector_PinHeader_2.54mm:PinHeader_1x02_P2.54mm_Vertical | ~
R1,R2 | 2 | 10k |  |  |  | Resistor_SMD:R_0805_2012Metric_Pad1.20x1.40mm_HandSolder | ~
U1 | 1 | SHT35-DIS |  |  |  | Sensor_Humidity:Sensirion_DFN-8-1EP_2.5x2.5mm_P0.5mm_EP1.1x1.7mm | https://www.sensirion.com/fileadmin/user_upload/customers/sensirion/Dokumente/2_Humidity_Sensors/Datasheets/Sensirion_Humidity_Sensors_SHT3x_Datasheet_digital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

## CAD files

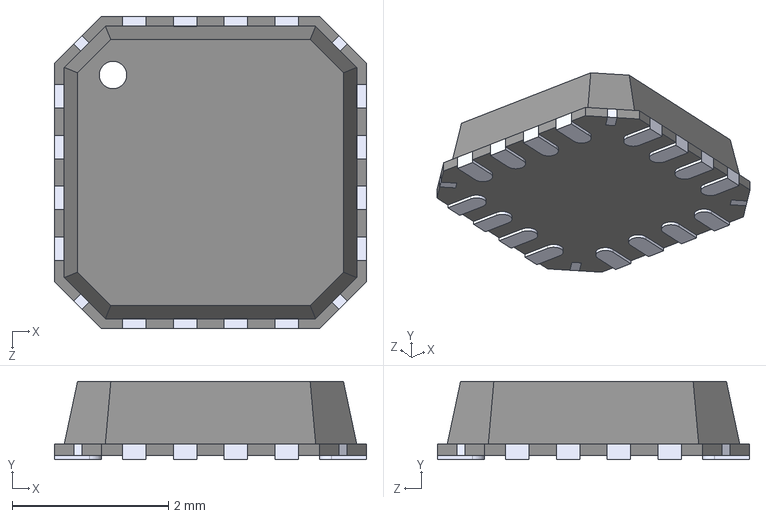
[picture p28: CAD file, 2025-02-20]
pcb/AD8426ACPZ-R7/AD8426ACPZ-R7.step
4.00 x 1.00 x 4.00 mm

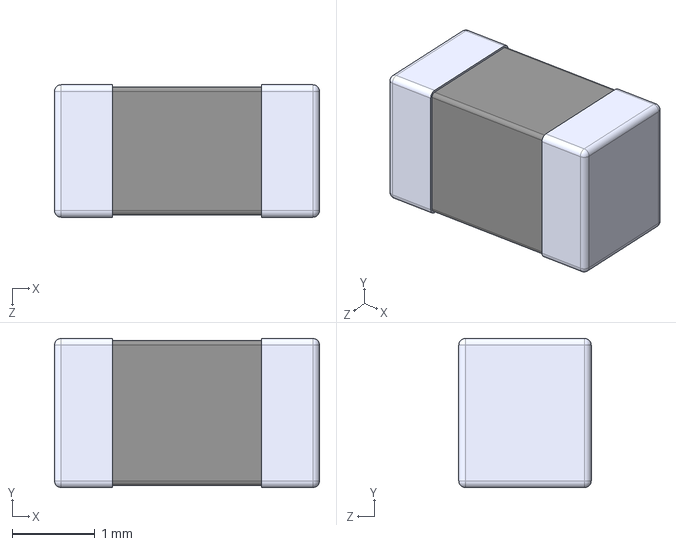
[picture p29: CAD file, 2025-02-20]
pcb/BLM31KN471SH1L/BLM31KN471SH1L.step
3.20 x 1.80 x 1.60 mm

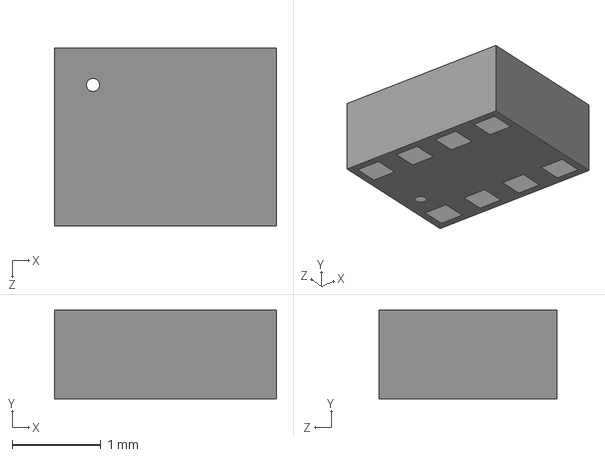
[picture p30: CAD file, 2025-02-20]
pcb/DPS310XTSA1/DPS310XTSA1.step
2.50 x 1.00 x 2.00 mm

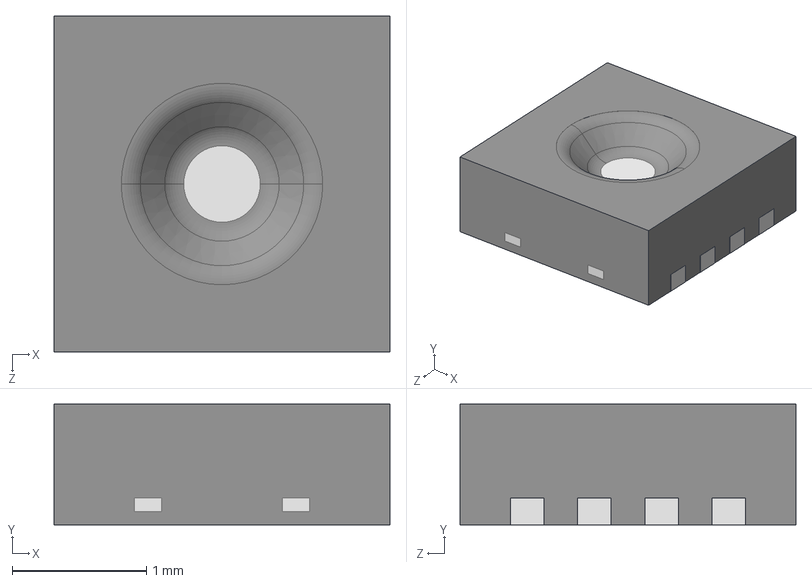
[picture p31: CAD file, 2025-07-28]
projects/Weather_Station/pcbs/SHT35_Board/SHT35_DIS_B2_5KS/SHT35-DIS-B2.5KS.STEP
2.50 x 0.901 x 2.50 mm

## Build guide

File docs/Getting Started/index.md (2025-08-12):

---
title: Getting Started
layout: default
nav_order: 2
permalink: /getting-started/
---

# Getting Started
{: .fs-8 .fw-500 .no_toc}
---

Follow these steps to begin developing your projects with SensEdu.
{: .fw-500}

{: .NOTE}
*If you prefer video tutorials, we have an [installation guide] on YouTube (not yet).*

**Step 1**{: .text-green-200} : Connect SensEdu Shield to the Arduino GIGA R1. **By default, the power and speakers are disabled.** To enable them, place a small [2-pin jumper](https://mou.sr/41uQmLm) onto headers **J18**, **J17**, and **J8**, according to the desired settings. The standard configuration is shown in the figure below (more details in [PCB section]({% link PCB/index.md%}#key-headersjumpers))


{: .text-center}

**Step 2**{: .text-green-200} : Download and Install [Arduino IDE]

**Step 3**{: .text-green-200} : Open the *Boards Manager* tab, search for `giga` and install the latest version of *Arduino Mbed OS Giga Boards* package

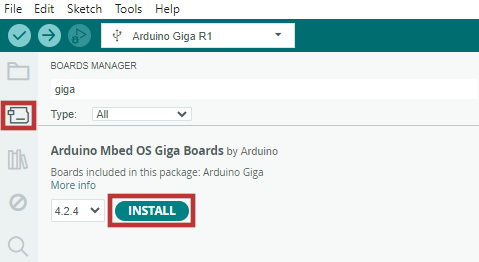
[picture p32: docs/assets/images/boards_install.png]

{: .text-center}

**Step 4**{: .text-green-200} : Download the latest [SensEdu release]

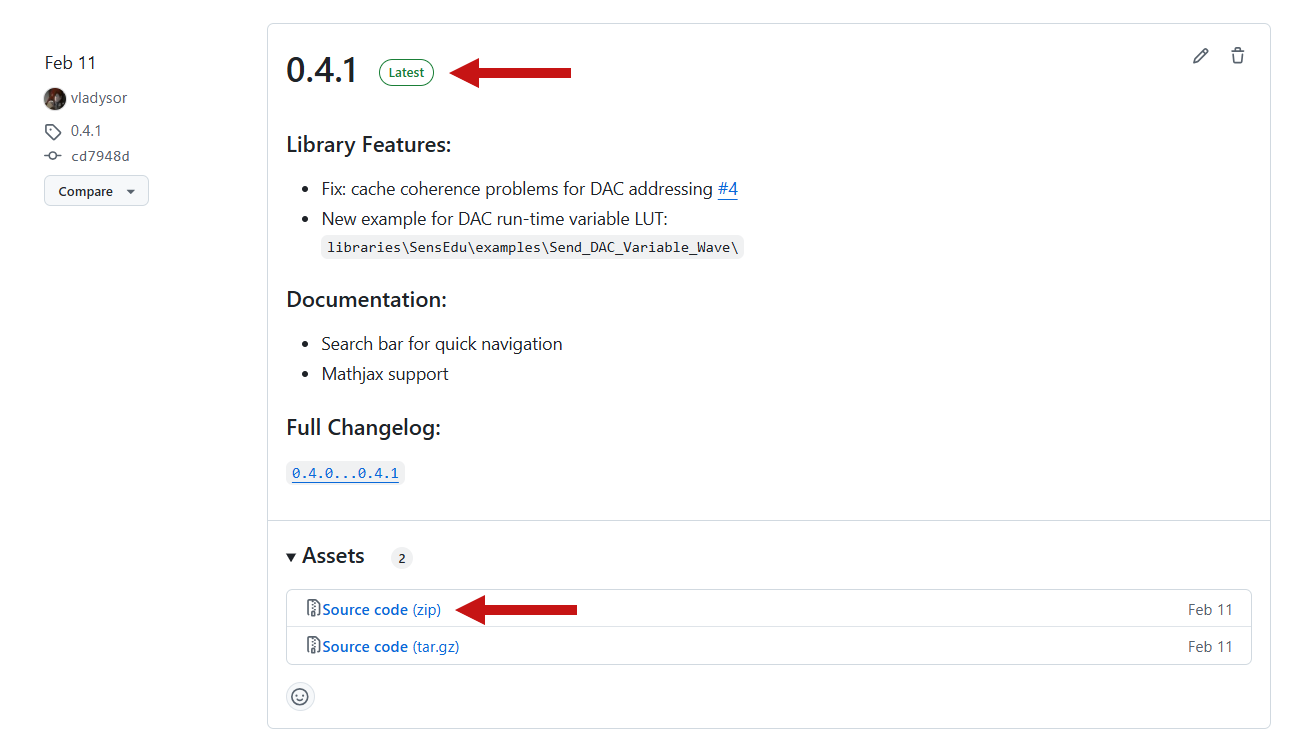
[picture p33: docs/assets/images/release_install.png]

{: .text-center}

**Step 5**{: .text-green-200} : Unzip downloaded files to a preferred location on your system

<video muted controls playsinline>
    <source src="{{site.baseurl}}/assets/videos/install_unzip.mp4" type="video/mp4">
    Video is broken.
</video>

**Step 6**{: .text-green-200} : Move extracted contents of `library` folder to the Arduino folder `My Documents\Arduino\libraries\`

<video muted controls playsinline>
    <source src="{{site.baseurl}}/assets/videos/install_libs.mp4" type="video/mp4">
    Video is broken.
</video>

**Step 7**{: .text-green-200} : Navigate to `File → Examples → SensEdu` and select `Blink_Delay` example

**Step 8**{: .text-green-200} : Select `Arduino Giga R1` board and corresponding COM port

**Step 9**{: .text-green-200} : Click **Upload** to compile and upload the sketch to your board. If the built-in LED starts blinking, the setup was successful!

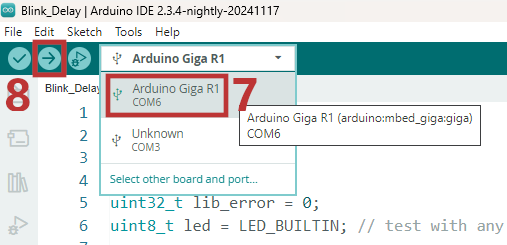
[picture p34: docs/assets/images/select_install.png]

{: .text-center}


{: .text-center}

## Post-Setup

Now that your setup is complete, you can start developing your projects with SensEdu! Here are some next steps to get started:
* Explore the [Library]({% link Library/index.md %}) wiki section for detailed examples of each peripheral
* Check out sample projects in `projects\` folder, and respective [Projects]({% link Projects/index.md %}) section
* For troubleshooting or guidance, visit the [Help]({% link Help/index.md %}) section

{: .NOTE}
If you are interested in contributing to SensEdu, visit the [Contributing]({% link Contributing/index.md %}) page and join our community!

[Arduino IDE]: https://support.arduino.cc/hc/en-us/articles/360019833020-Download-and-install-Arduino-IDE
[SensEdu release]: https://github.com/ShiegeChan/SensEdu/releases/
[installation guide]: https://www.youtube.com/

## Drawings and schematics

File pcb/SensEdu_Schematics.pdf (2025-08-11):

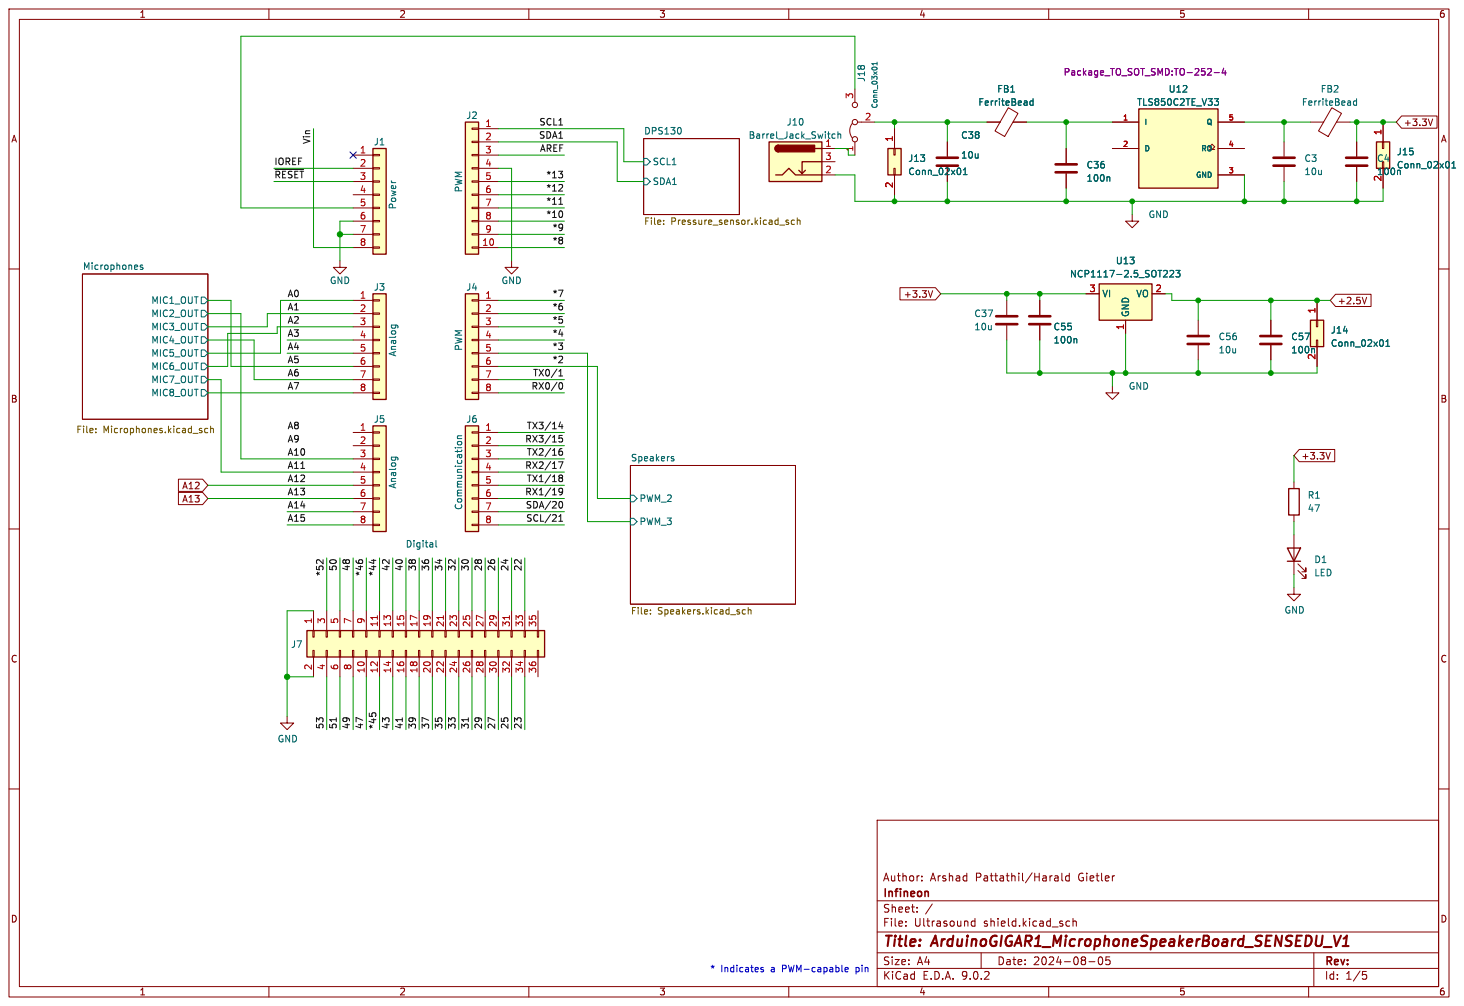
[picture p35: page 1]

SDA1 SCL1 DPS130 File: Pressure_sensor.kicad_sch MIC1_OUT MIC2_OUT MIC4_OUT MIC3_OUT MIC7_OUT MIC8_OUT MIC5_OUT MIC6_OUT Microphones File: Microphones.kicad_sch

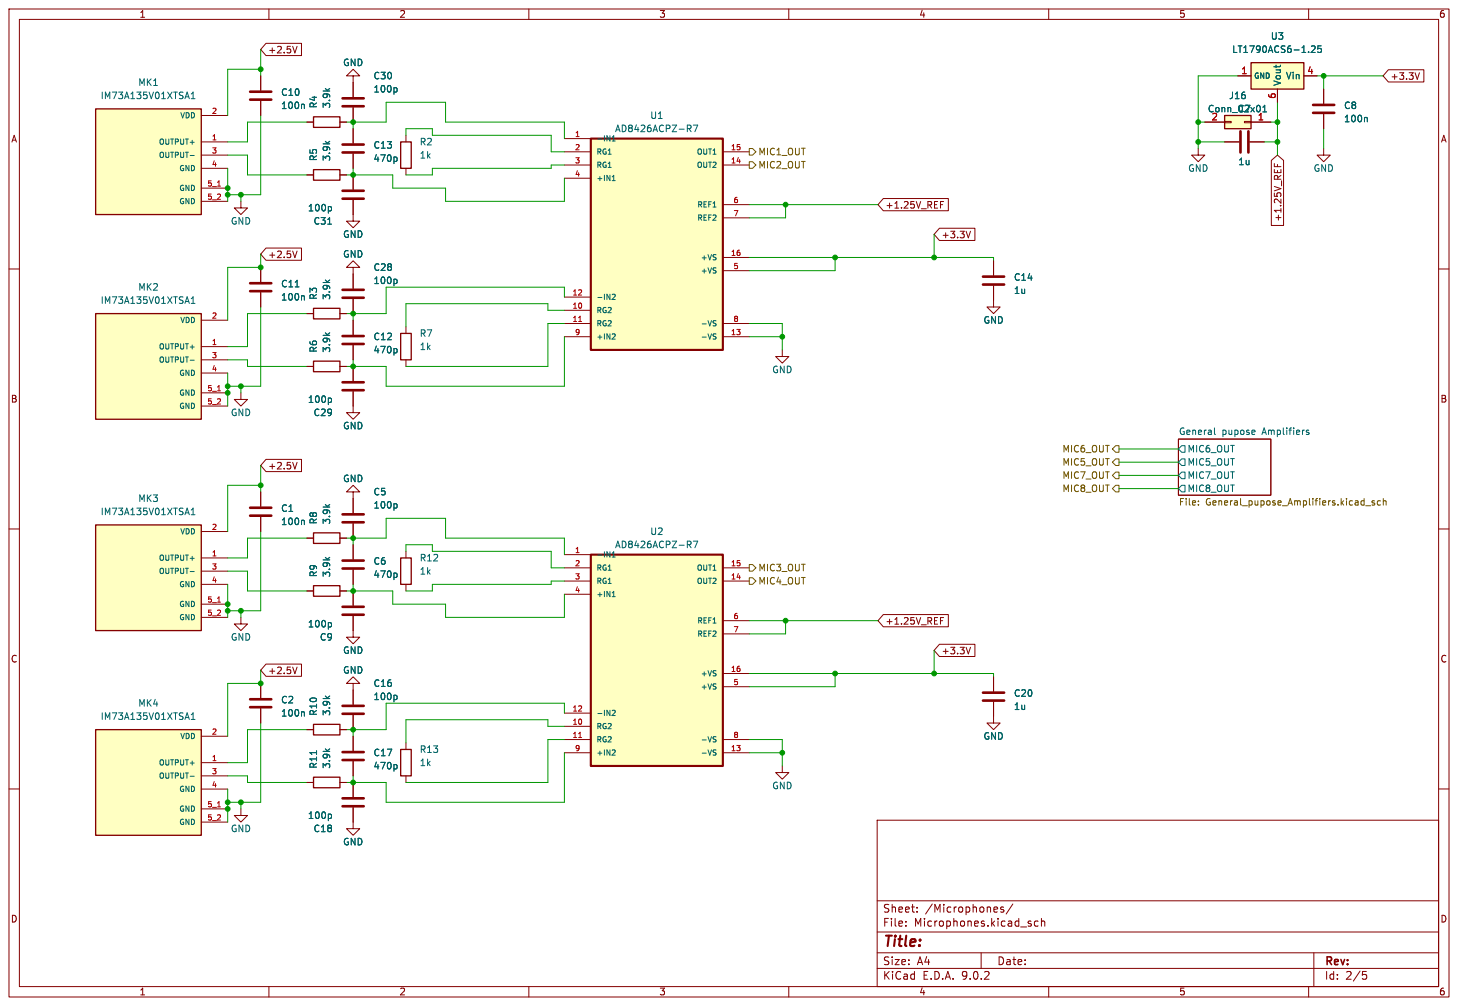
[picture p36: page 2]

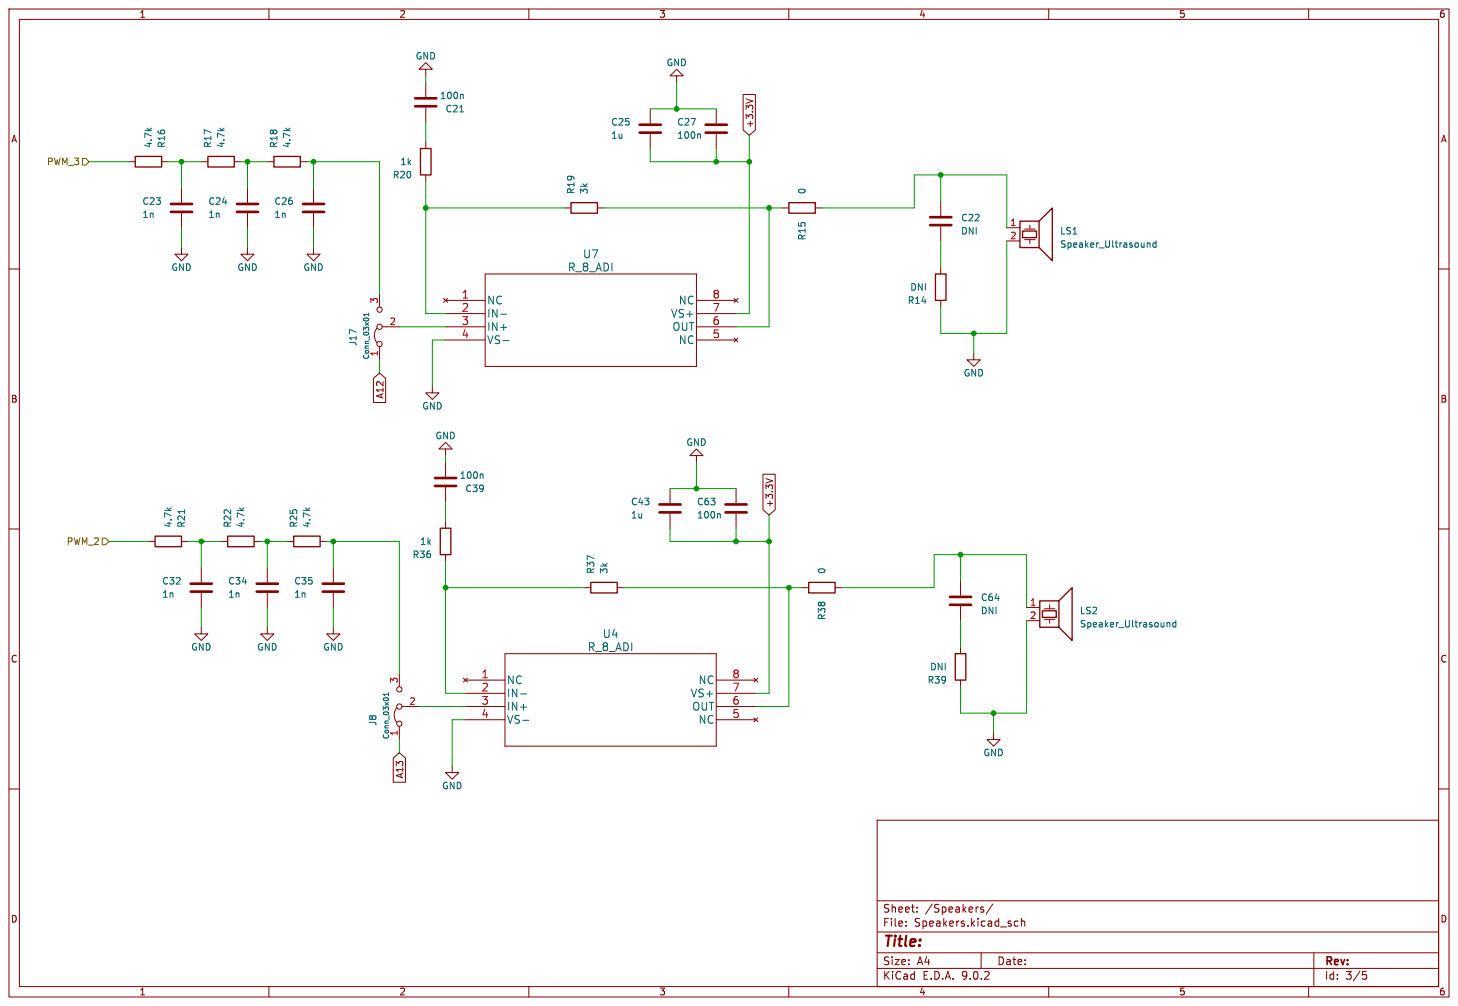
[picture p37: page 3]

Id: 3/5 Title: File: Speakers.kicad_sch Sheet: /Speakers/ C63

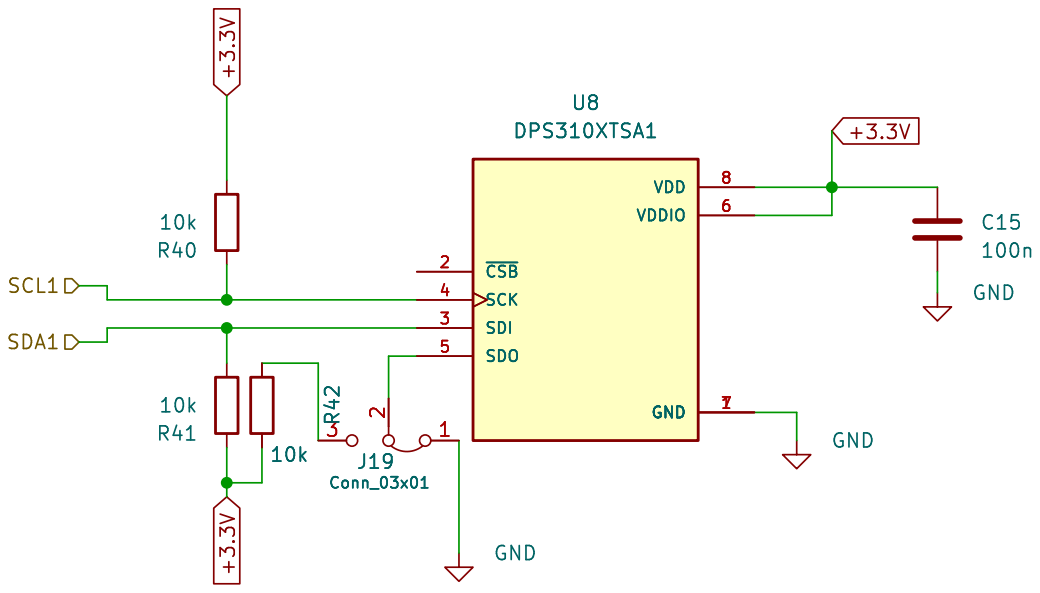
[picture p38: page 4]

Id: 5/5 Title: File: Pressure_sensor.kicad_sch Sheet: /DPS130/

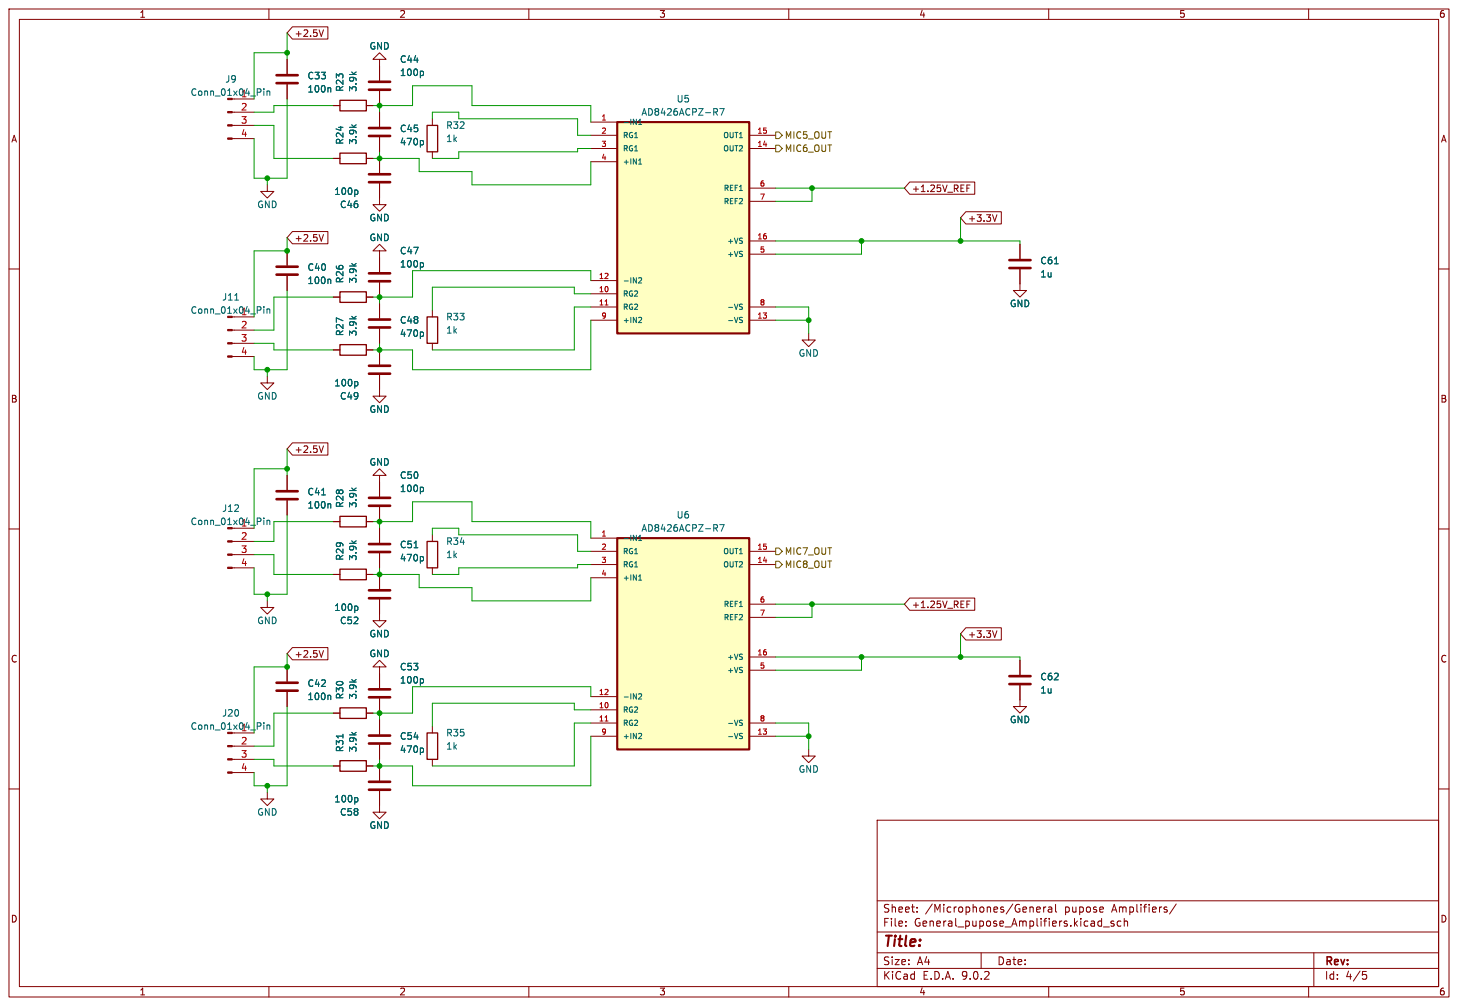
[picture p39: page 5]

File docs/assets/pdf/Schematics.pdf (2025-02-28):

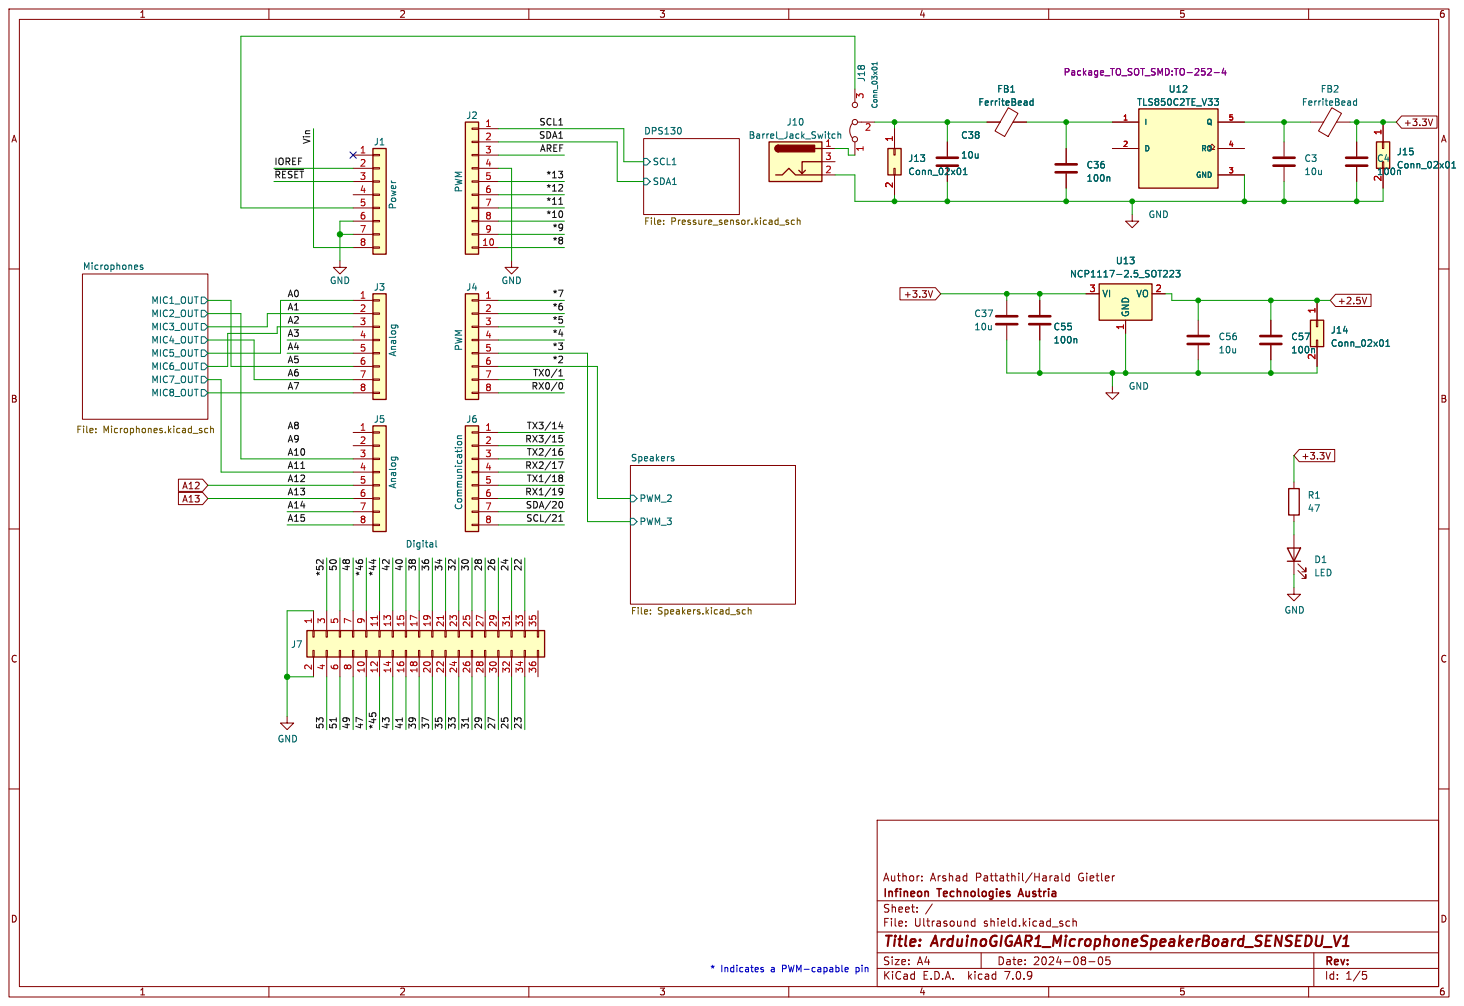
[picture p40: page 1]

SDA1 SCL1 DPS130 File: Pressure_sensor.kicad_sch MIC1_OUT MIC2_OUT MIC4_OUT MIC3_OUT MIC7_OUT MIC8_OUT MIC5_OUT MIC6_OUT Microphones File: Microphones.kicad_sch

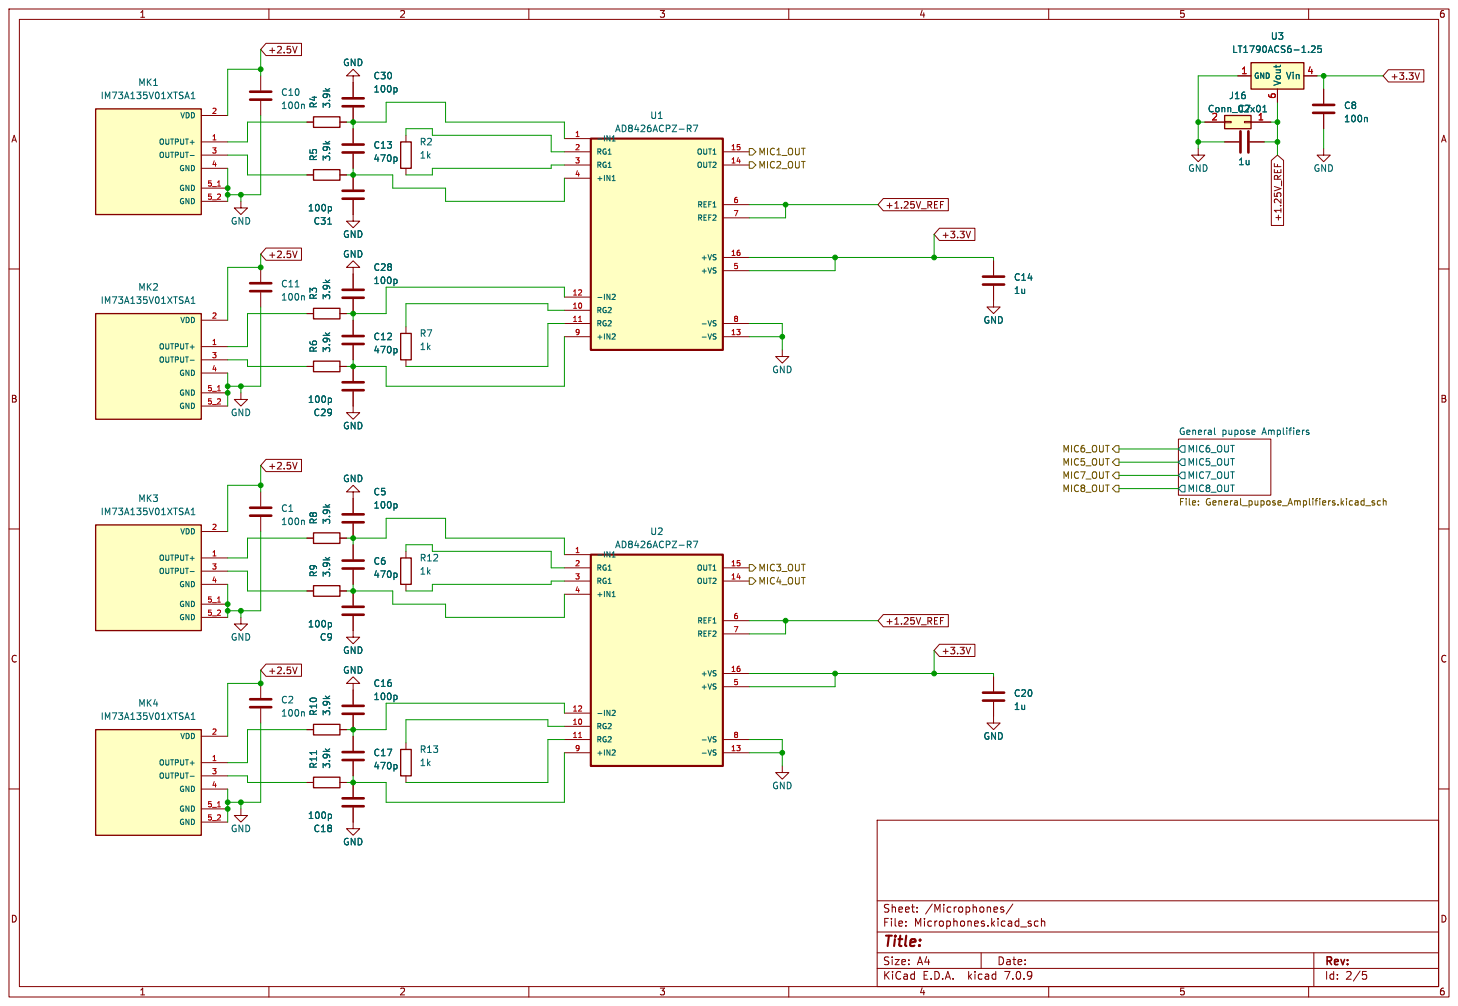
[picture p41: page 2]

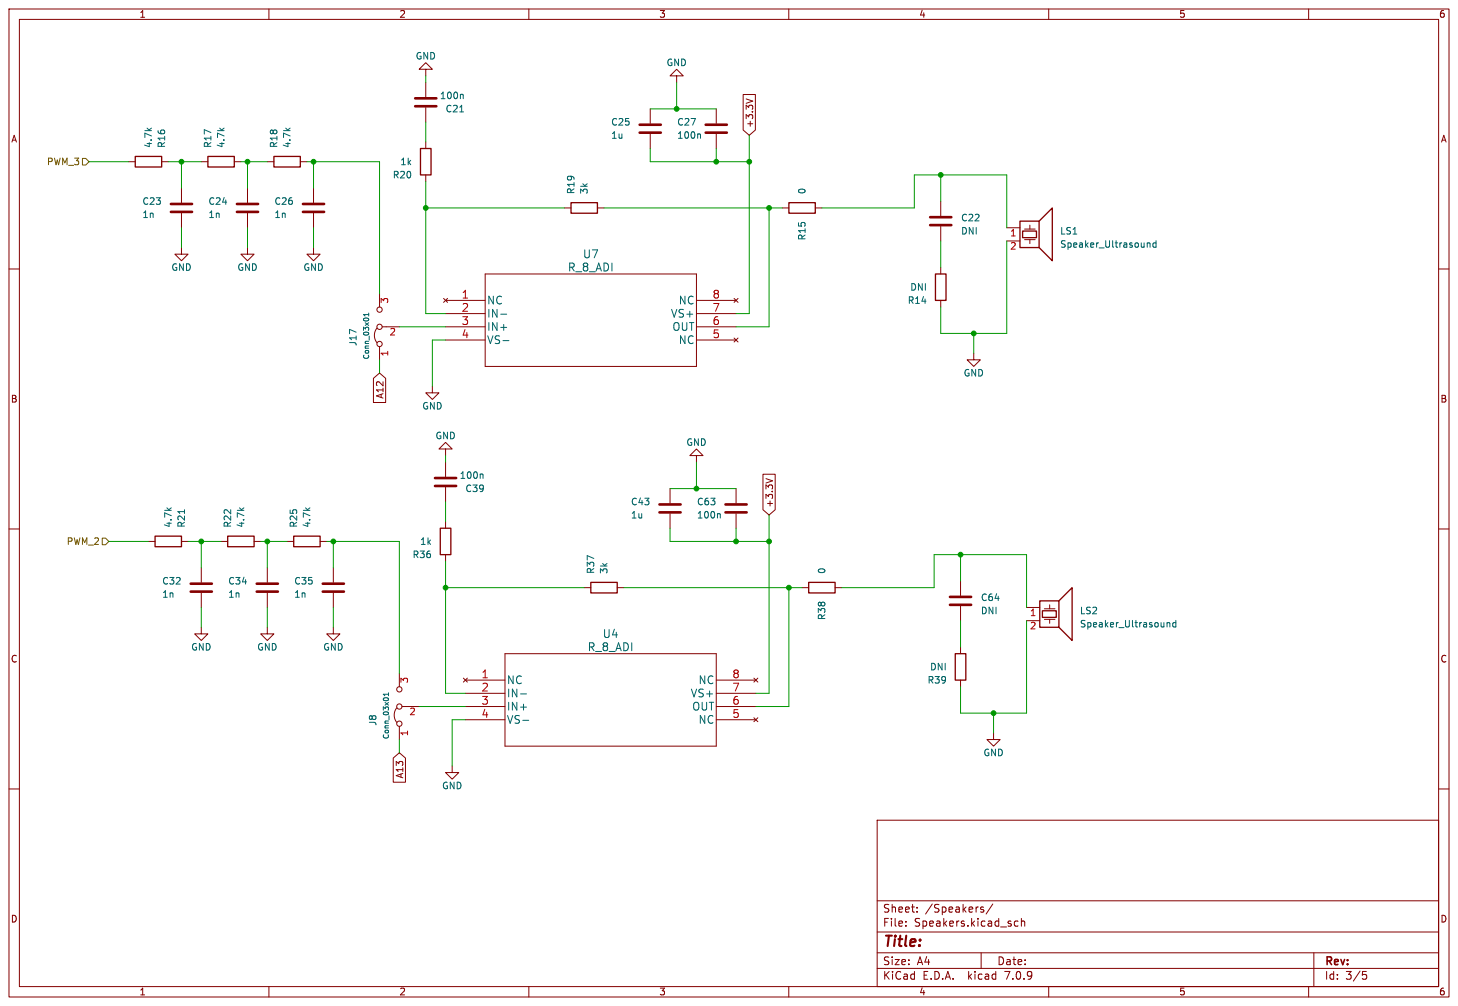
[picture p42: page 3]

Id: 3/5 Title: File: Speakers.kicad_sch Sheet: /Speakers/

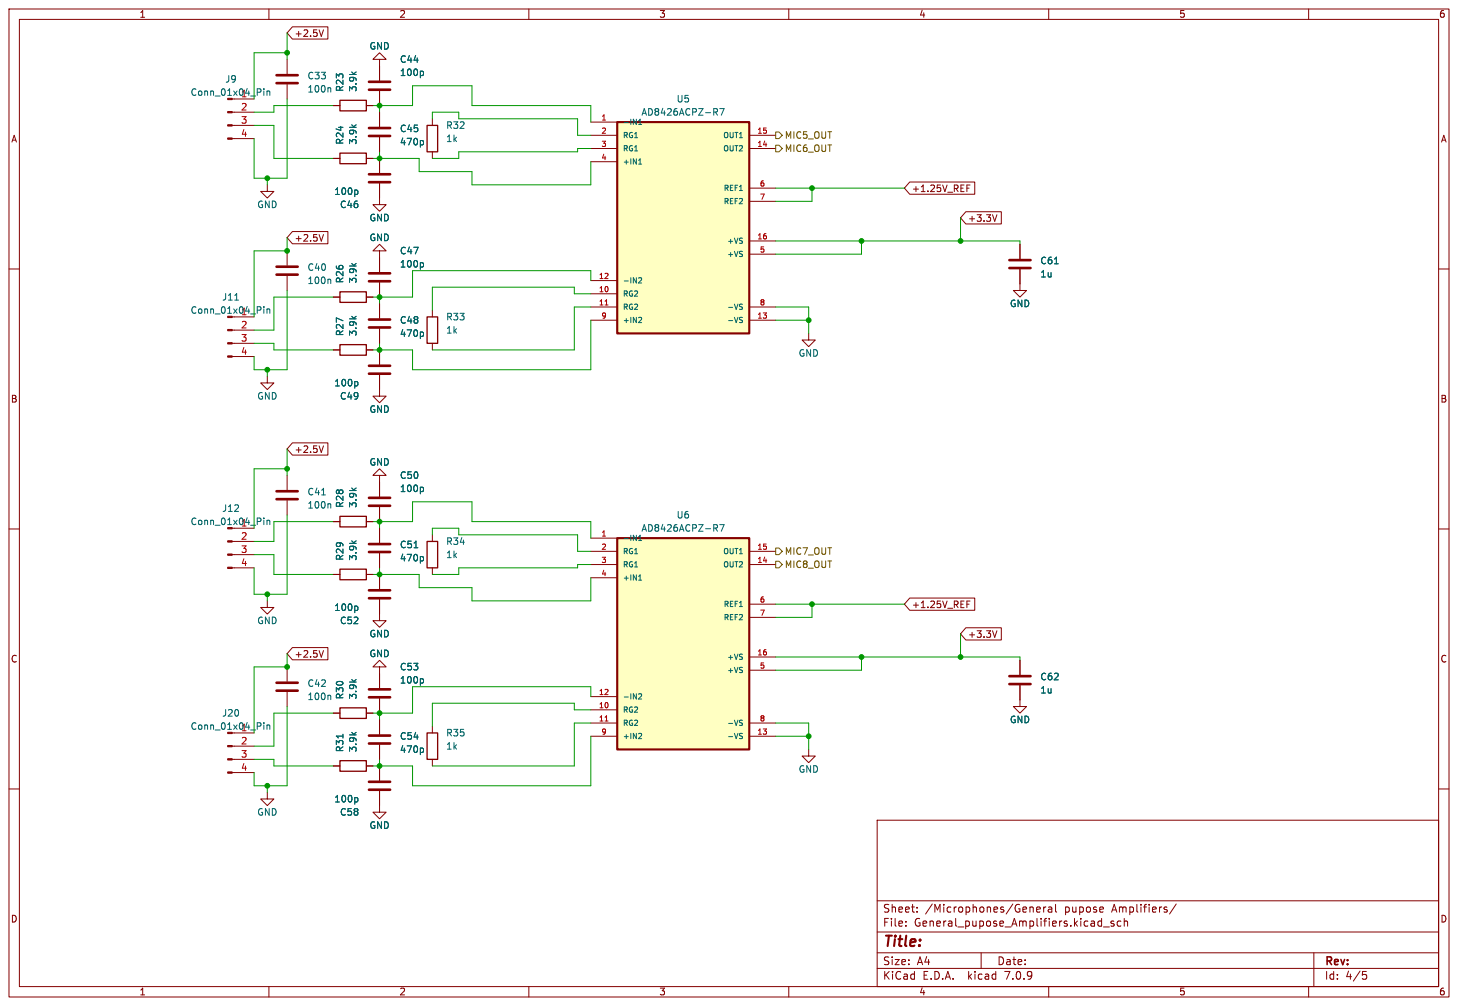
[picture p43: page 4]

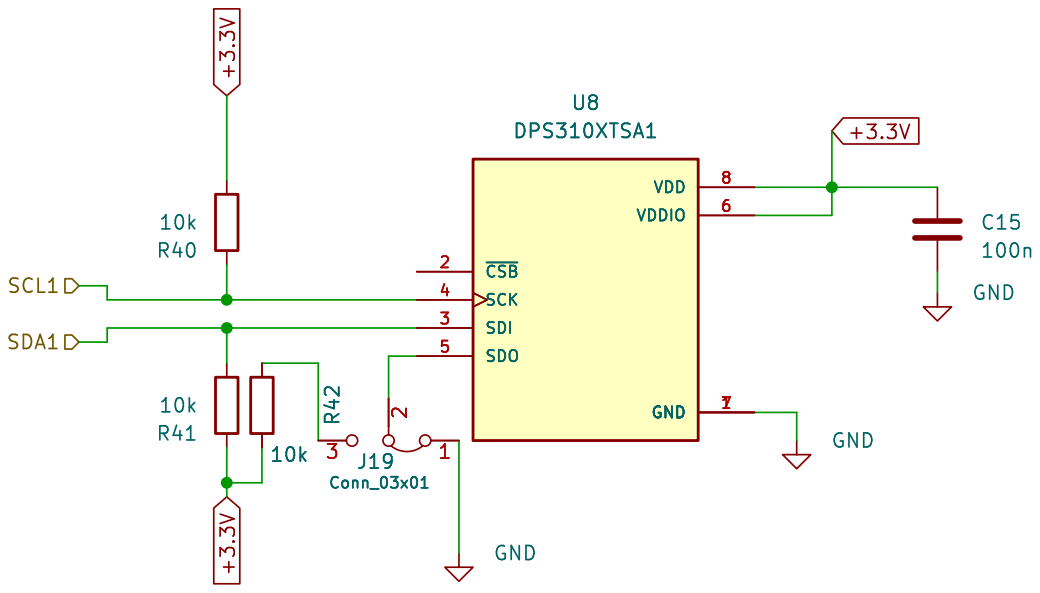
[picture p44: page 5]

Id: 5/5 Title: File: Pressure_sensor.kicad_sch Sheet: /DPS130/ GND

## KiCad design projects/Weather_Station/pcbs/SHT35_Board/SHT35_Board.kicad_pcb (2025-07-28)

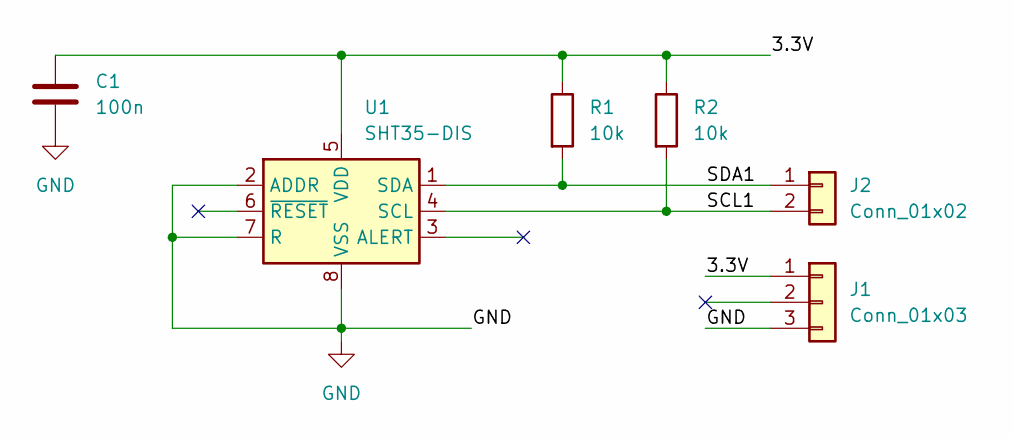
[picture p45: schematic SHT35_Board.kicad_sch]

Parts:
C1: 100n; C_0805_2012Metric_Pad1.18x1.45mm_HandSolder
J1: Conn_01x03; PinHeader_1x03_P2.54mm_Vertical
J2: Conn_01x02; PinHeader_1x02_P2.54mm_Vertical
R1, R2: 10k; R_0805_2012Metric_Pad1.20x1.40mm_HandSolder
U1: SHT35-DIS; Sensirion_DFN-8-1EP_2.5x2.5mm_P0.5mm_EP1.1x1.7mm

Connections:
/3.3V: C1.1, J1.1, R1.1, R2.1, U1.5 (VDD)
/SCL1: J2.2, R2.2, U1.4 (SCL)
/SDA1: J2.1, R1.2, U1.1 (SDA)
GND: C1.2, J1.3, U1.2 (ADDR), U1.7 (R), U1.8 (VSS), U1.9 (VSS)

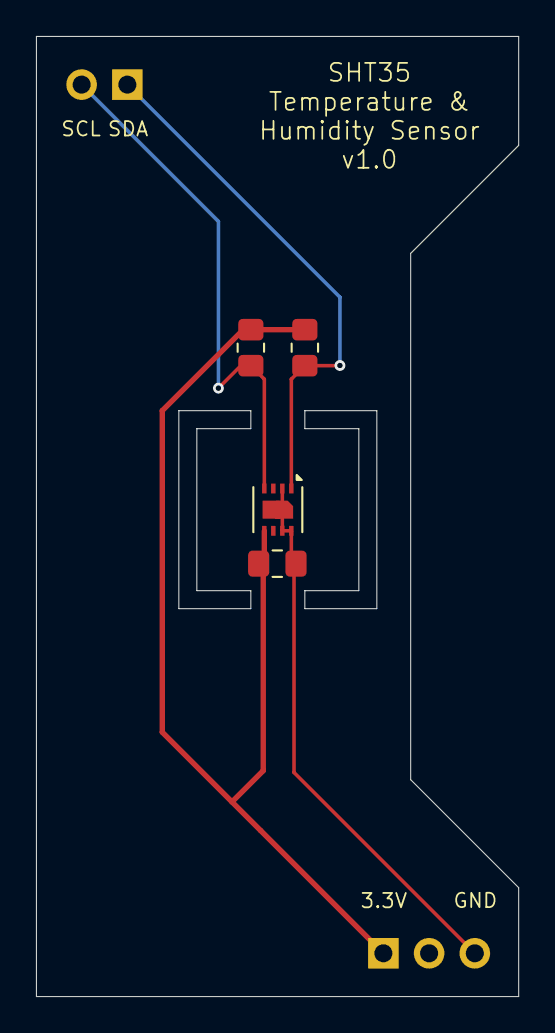
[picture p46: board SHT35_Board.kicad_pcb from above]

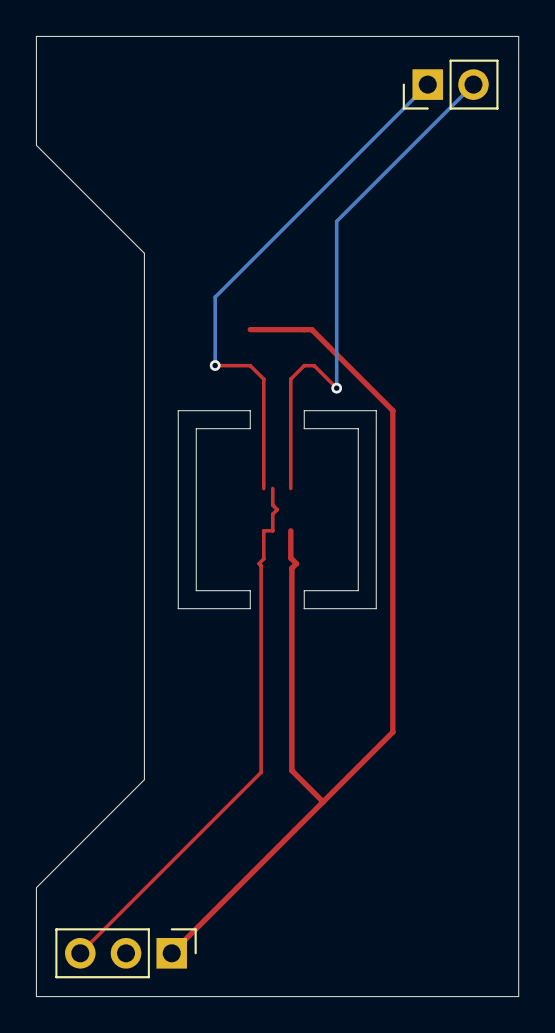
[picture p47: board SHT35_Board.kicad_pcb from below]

Board: 2 copper layers, 26.8 x 53.3 mm, 6 parts (2 on the bottom side), 4 nets.

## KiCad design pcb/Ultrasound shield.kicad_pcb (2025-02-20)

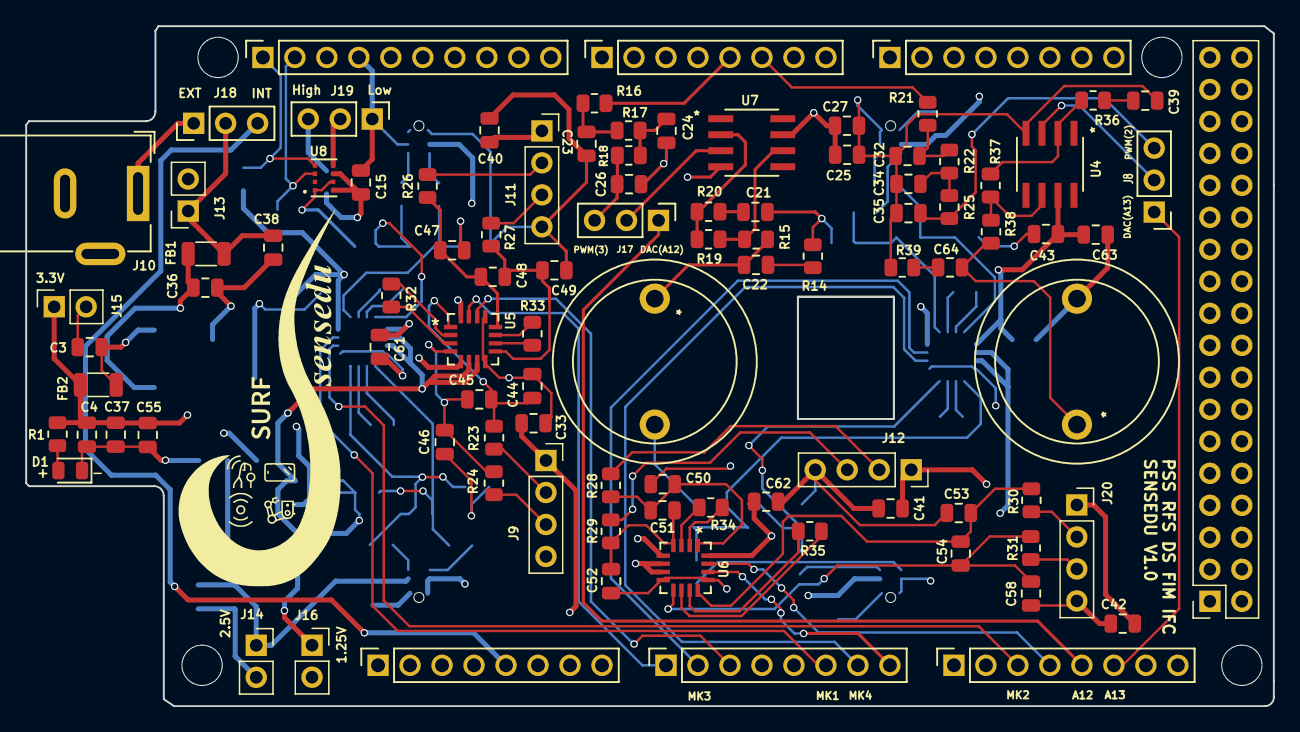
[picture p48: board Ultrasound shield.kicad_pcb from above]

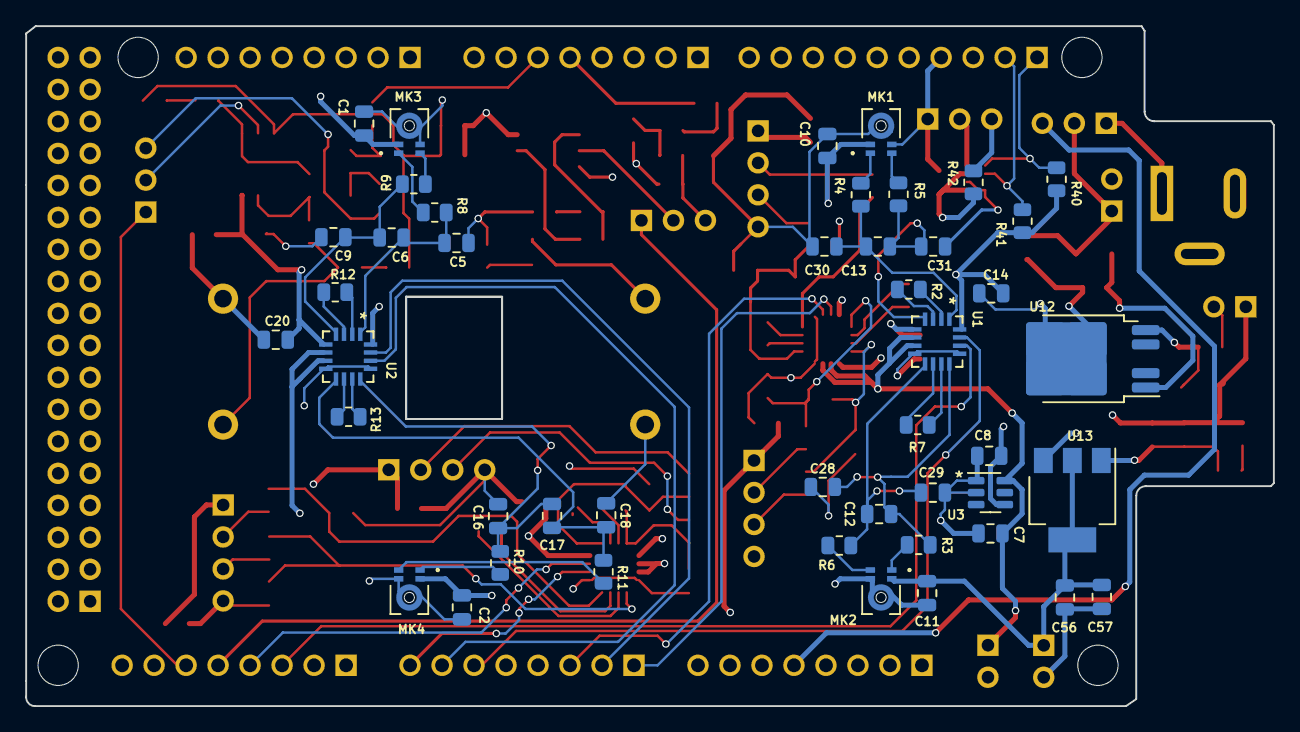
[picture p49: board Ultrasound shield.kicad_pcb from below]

Board: 4 copper layers, 99.1 x 54.0 mm, 146 parts (46 on the bottom side), 92 nets.

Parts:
C1, C2, C4, C8, C10, C11, C15, C21, C27, C33, C36, C39, C40, C41, C42, C55, C57, C63: 100n; C_0805_2012Metric
C3, C37, C38, C56: 10u; C_0805_2012Metric
C5, C9, C16, C18, C28, C29, C30, C31, C44, C46, C47, C49, C50, C52, C53, C58: 100p; C_0805_2012Metric
C6, C12, C13, C17, C45, C48, C51, C54: 470p; C_0805_2012Metric
C7, C14, C20, C25, C43, C61, C62: 1u; C_0805_2012Metric
C22, C64: DNI; C_0805_2012Metric
C23, C24, C26, C32, C34, C35: 1n; C_0805_2012Metric
D1: LED; LED_0805_2012Metric
FB1, FB2: FerriteBead; L_1206_3216Metric12
J1: Power; PinSocket_1x08_P2.54mm_Vertical
J2: PWM; PinSocket_1x10_P2.54mm_Vertical
J3, J5: Analog; PinSocket_1x08_P2.54mm_Vertical
J4: PWM; PinSocket_1x08_P2.54mm_Vertical
J6: Communication; PinSocket_1x08_P2.54mm_Vertical
J7: Digital; PinSocket_2x18_P2.54mm_Vertical
J8, J17, J18, J19: Conn_03x01; PinHeader_1x03_P2.54mm_Vertical
J9, J11, J12, J20: Conn_01x04_Pin; PinSocket_1x04_P2.54mm_Vertical
J10: Barrel_Jack_Switch; BarrelJack_Wuerth_6941xx301002
J13, J14, J15, J16: Conn_02x01; PinSocket_1x02_P2.54mm_Vertical
LS1, LS2: Speaker_Ultrasound; 328ST16M_Speaker
MH1, MH2, MH5, MH6: MountingHole_3.2mm
MK1, MK2, MK3, MK4: IM73A135V01XTSA1; MIC_IM73A135V01XTSA1
R1: 47; R_0805_2012Metric
R2, R7, R12, R13, R20, R32, R33, R34, R35, R36: 1k; R_0805_2012Metric
R3, R4, R5, R6, R8, R9, R10, R11, R23, R24, R26, R27, R28, R29, R30, R31: 3.9k; R_0805_2012Metric
R14, R39: DNI; R_0805_2012Metric
R15, R38: 0; R_0805_2012Metric
R16, R17, R18, R21, R22, R25: 4.7k; R_0805_2012Metric
R19, R37: 3k; R_0805_2012Metric
R40, R41, R42: 10k; R_0805_2012Metric
U1, U2, U5, U6: AD8426ACPZ-R7; QFN65P400X400X100-16N
U3: LT1790ACS6-1.25; TSOT-23-6
U4, U7: R_8_ADI; ADA4891-1ARZ
U8: DPS310XTSA1; XDCR_DPS310XTSA1
U12: TLS850C2TE_V33; TO-252-4
U13: NCP1117-2.5_SOT223; SOT-223-3_TabPin2

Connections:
+1.25V_REF: C7.2, J16.1, U1.6 (REF1), U1.7 (REF2), U2.6 (REF1), U2.7 (REF2), U3.6 (Vout), U5.6 (REF1), U5.7 (REF2), U6.6 (REF1), U6.7 (REF2)
+2.5V: C1.1, C2.1, C10.1, C11.1, C33.1, C40.1, C41.1, C42.1, C56.1, C57.1, J9.1, J11.1, J12.1, J14.1, J20.1, MK1.2 (VDD), MK2.2 (VDD), MK3.2 (VDD), MK4.2 (VDD), U13.2 (VO)
+3.3V: C4.1, C8.1, C14.1, C15.1, C20.1, C25.2, C27.2, C37.1, C43.2, C55.1, C61.1, C62.1, C63.2, FB2.2, J15.1, R1.1, R40.2, R41.1, R42.2, U1.5 (+VS), U1.16 (+VS), U2.5 (+VS), U2.16 (+VS), U3.4 (Vin), U4.7 (VS+), U5.5 (+VS), U5.16 (+VS), U6.5 (+VS), U6.16 (+VS), U7.7 (VS+), U8.6 (VDDIO), U8.8 (VDD), U13.3 (VI)
/*2: J4.6, R21.2
/*3: J4.5, R16.2
/A0: J3.1, U5.15 (OUT1)
/A1: J3.2, U2.15 (OUT1)
/A2: J3.3, U5.14 (OUT2)
/A5: J3.6, U1.15 (OUT1)
/A6: J3.7, U2.14 (OUT2)
/A7: J3.8, U6.14 (OUT2)
/A10: J5.3, U1.14 (OUT2)
/A11: J5.4, U6.15 (OUT1)
/SCL1: J2.1, R40.1, U8.4 (SCK)
/SDA1: J2.2, R41.2, U8.3 (SDI)
A12: J5.5, J17.1 (A)
A13: J5.6, J8.1 (A)
GND: C1.2, C2.2, C3.2, C4.2, C5.1, C7.1, C8.2, C9.1, C10.2, C11.2, C14.2, C15.2, C16.1, C18.1, C20.2, C21.2, C23.2, C24.2, C25.1, C26.2, C27.1, C28.1, C29.1, C30.1, C31.1, C32.2, C33.2, C34.2, C35.2, C36.2, C37.2, C38.2, C39.2, C40.2, C41.2, C42.2, C43.1, C44.1, C46.1, C47.1, C49.1, C50.1, C52.1, C53.1, C55.2, C56.2, C57.2, C58.1, C61.2, C62.2, C63.1, D1.1 (K), J1.6, J1.7, J2.4, J7.1, J7.2, J9.4, J10.2, J11.4, J12.4, J13.2, J14.2, J15.2, J16.2, J19.1 (A), J20.4, LS1.2, LS2.2, MK1.4 (GND), MK1.5_1 (GND), MK1.5_2 (GND), MK2.4 (GND), MK2.5_1 (GND), MK2.5_2 (GND), MK3.4 (GND), MK3.5_1 (GND), MK3.5_2 (GND), MK4.4 (GND), MK4.5_1 (GND), MK4.5_2 (GND), R14.1, R39.1, U1.8 (-VS), U1.13 (-VS), U2.8 (-VS), U2.13 (-VS), U3.1 (GND), U3.2 (GND), U4.4 (VS-), U5.8 (-VS), U5.13 (-VS), U6.8 (-VS), U6.13 (-VS), U7.4 (VS-), U8.1 (GND), U8.7 (GND), U12.3 (GND), U13.1 (GND)
unnamed: C21.1, R20.2
unnamed: C22.1, LS1.1, R15.2
unnamed: C22.2, R14.2
unnamed: C23.1, R16.1, R17.1
unnamed: C24.1, R17.2, R18.1
unnamed: C32.1, R21.1, R22.1
unnamed: C34.1, R22.2, R25.1
unnamed: C39.1, R36.2
unnamed: C64.1, LS2.1, R38.2
unnamed: C64.2, R39.2
unnamed: D1.2 (A), R1.2
unnamed: J1.5, J18.3 (B)
unnamed: C35.1, J8.3 (B), R25.2
unnamed: J8.2 (C), U4.3 (IN+)
unnamed: J9.2, R23.1
unnamed: J9.3, R24.1
unnamed: J11.2, R26.1
unnamed: J11.3, R27.1
unnamed: J12.2, R28.1
unnamed: J12.3, R29.1
unnamed: C38.1, FB1.1, J13.1, J18.2 (C)
unnamed: C26.1, J17.3 (B), R18.2
unnamed: J17.2 (C), U7.3 (IN+)
unnamed: J10.1, J18.1 (A)
unnamed: J19.3 (B), R42.1
unnamed: J19.2 (C), U8.5 (SDO)
unnamed: J20.2, R30.1
unnamed: J20.3, R31.1
unnamed: MK1.1 (OUTPUT+), R4.1
unnamed: MK1.3 (OUTPUT-), R5.1
unnamed: MK2.1 (OUTPUT+), R3.1
unnamed: MK2.3 (OUTPUT-), R6.1
unnamed: MK3.1 (OUTPUT+), R8.1
unnamed: MK3.3 (OUTPUT-), R9.1
unnamed: MK4.1 (OUTPUT+), R10.1
unnamed: MK4.3 (OUTPUT-), R11.1
unnamed: R2.1, U1.2 (RG1)
unnamed: R2.2, U1.3 (RG1)
unnamed: R7.1, U1.10 (RG2)
unnamed: R7.2, U1.11 (RG2)
unnamed: R12.1, U2.2 (RG1)
unnamed: R12.2, U2.3 (RG1)
unnamed: R13.1, U2.10 (RG2)
unnamed: R13.2, U2.11 (RG2)
unnamed: R32.1, U5.2 (RG1)
unnamed: R32.2, U5.3 (RG1)
unnamed: R33.1, U5.10 (RG2)
unnamed: R33.2, U5.11 (RG2)
unnamed: R34.1, U6.2 (RG1)
unnamed: R34.2, U6.3 (RG1)
unnamed: R35.1, U6.10 (RG2)
unnamed: R35.2, U6.11 (RG2)
unnamed: C13.2, C31.2, R5.2, U1.4 (+IN1)
unnamed: C12.2, C29.2, R6.2, U1.9 (+IN2)
unnamed: C13.1, C30.2, R4.2, U1.1 (-IN1)
unnamed: C12.1, C28.2, R3.2, U1.12 (-IN2)
unnamed: C6.2, C9.2, R9.2, U2.4 (+IN1)
unnamed: C17.2, C18.2, R11.2, U2.9 (+IN2)
unnamed: C5.2, C6.1, R8.2, U2.1 (-IN1)
unnamed: C16.2, C17.1, R10.2, U2.12 (-IN2)
unnamed: R36.1, R37.1, U4.2 (IN-)
unnamed: R37.2, R38.1, U4.6 (OUT)
unnamed: C45.2, C46.2, R24.2, U5.4 (+IN1)
unnamed: C48.2, C49.2, R27.2, U5.9 (+IN2)
unnamed: C44.2, C45.1, R23.2, U5.1 (-IN1)
unnamed: C47.2, C48.1, R26.2, U5.12 (-IN2)
unnamed: C51.2, C52.2, R29.2, U6.4 (+IN1)
unnamed: C54.2, C58.2, R31.2, U6.9 (+IN2)
unnamed: C50.2, C51.1, R28.2, U6.1 (-IN1)
unnamed: C53.2, C54.1, R30.2, U6.12 (-IN2)
unnamed: R19.1, R20.1, U7.2 (IN-)
unnamed: R15.1, R19.2, U7.6 (OUT)
unnamed: C36.1, FB1.2, U12.1 (I)
unnamed: C3.1, FB2.1, U12.5 (Q)

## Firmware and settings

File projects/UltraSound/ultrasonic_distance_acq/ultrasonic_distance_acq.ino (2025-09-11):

#include "SensEdu.h"
#include "CMSIS_DSP.h"
#include "SineLUT.h"
#include "FilterTaps.h"
#include "DACWave.h" // contains wave and its size

uint32_t lib_error = 0;
uint8_t error_led = D86;

#define AIR_SPEED               343
#define AIR_SPEED_MM_S          (AIR_SPEED * 1000UL)
#define AIR_SPEED_UM_S          (AIR_SPEED * 1000000UL)
#define HALF_AIR_SPEED_MM_S     (AIR_SPEED_MM_S / 2U)
#define HALF_AIR_SPEED_UM_S     (AIR_SPEED_UM_S / 2U)

/* -------------------------------------------------------------------------- */
/*                                  Settings                                  */
/* -------------------------------------------------------------------------- */
#define BAN_DISTANCE	            20	    // min distance [cm] - how many self reflections cancelled
#define ACTUAL_SAMPLING_RATE        250000  // You need to measure this value using a wave generator with a fixed e.g. 1kHz Sine
#define STORE_BUF_SIZE              32 * 32 // 2400 for 1 measurement per second. 
                            	        // only multiples of 32!!!!!! (64 chunk size of bytes, so 32 for 16bit)

/* --------------------------------- Filter --------------------------------- */
#define FILTER_BLOCK_LENGTH     32      // how many samples we want to process every time we call the fir process function AT
#define FILTER_TAP_NUM          32      // tap number for the bandpass filter

static float32_t firStateBuffer[FILTER_BLOCK_LENGTH + FILTER_TAP_NUM - 1]; // current filter state buffer
arm_fir_instance_f32 Fir_filt; // creating an object instance

/* ----------------------------------- ADC ---------------------------------- */
ADC_TypeDef* adc1 = ADC1;
ADC_TypeDef* adc2 = ADC2;

const uint8_t adc1_mic_num = 2; // 2 microphones for adc1
const uint8_t adc2_mic_num = 2; // 2 microphones for adc2

uint8_t adc1_pins[adc1_mic_num] = {A5, A10}; // mic1 and mic2
uint8_t adc2_pins[adc2_mic_num] = {A1, A6}; // mic3 and mic4 

// must be:
// 1. multiple of 32 words (64 half-words) to ensure cache coherence
// 2. properly aligned
const uint16_t adc1_data_size = STORE_BUF_SIZE * adc1_mic_num;
const uint16_t adc2_data_size = STORE_BUF_SIZE * adc2_mic_num;
__attribute__((aligned(__SCB_DCACHE_LINE_SIZE))) uint16_t adc1_data[adc1_data_size];
__attribute__((aligned(__SCB_DCACHE_LINE_SIZE))) uint16_t adc2_data[adc2_data_size];

SensEdu_ADC_Settings adc1_settings = {
    .adc = adc1,
    .pins = adc1_pins,
    .pin_num = adc1_mic_num,

    .conv_mode = SENSEDU_ADC_MODE_CONT_TIM_TRIGGERED,
    .sampling_freq = 250000,
    
    .dma_mode = SENSEDU_ADC_DMA_CONNECT,
    .mem_address = (uint16_t*)adc1_data,
    .mem_size = adc1_data_size
};

SensEdu_ADC_Settings adc2_settings = {
    .adc = adc2,
    .pins = adc2_pins,
    .pin_num = adc2_mic_num,

    .conv_mode = SENSEDU_ADC_MODE_CONT_TIM_TRIGGERED,
    .sampling_freq = 250000,
    
    .dma_mode = SENSEDU_ADC_DMA_CONNECT,
    .mem_address = (uint16_t*)adc2_data,
    .mem_size = adc2_data_size
};

/* ----------------------------------- DAC ---------------------------------- */
DAC_Channel* dac_channel = DAC_CH1;
// lut settings are in SineLUT.h
#define DAC_SINE_FREQ     	32000                           // 32kHz
#define DAC_SAMPLE_RATE     DAC_SINE_FREQ * sine_lut_size   // 64 samples per one sine cycle

SensEdu_DAC_Settings dac_settings = {dac_channel, DAC_SAMPLE_RATE, (uint16_t*)sine_lut, sine_lut_size, 
    SENSEDU_DAC_MODE_BURST_WAVE, dac_cycle_num}; // specifying burst mode 

/* -------------------------------------------------------------------------- */
/*                                  Constants                                 */
/* -------------------------------------------------------------------------- */

const uint16_t air_speed = 343; // m/s

// e.g. 25cm ban means 0.25*2/343 time ban, then multiply by sample rate
const uint32_t c_banned_sample_num = ((BAN_DISTANCE*2*ACTUAL_SAMPLING_RATE)/air_speed)/100; 

/* -------------------------------------------------------------------------- */
/*                              Global Structure                              */
/* -------------------------------------------------------------------------- */
typedef struct {
	uint8_t ban_flag; // activate self reflections ban
	char serial_read_buf;
    float processing_buffer[STORE_BUF_SIZE]; // reusable float buffer for signal processing
    uint16_t channel_buffer[STORE_BUF_SIZE]; // data rearrangement
} SenseduBoard;

static SenseduBoard SenseduBoardObj;

/* -------------------------------------------------------------------------- */
/*                                    Setup                                   */
/* -------------------------------------------------------------------------- */

void setup() {
	SenseduBoard* main_obj_ptr = &SenseduBoardObj;
	main_obj_init(main_obj_ptr);

    // initializing the filter
    arm_fir_init_f32(&Fir_filt, FILTER_TAP_NUM, filter_taps, firStateBuffer, FILTER_BLOCK_LENGTH); 

    Serial.begin(115200);

    /* DAC */
    SensEdu_DAC_Init(&dac_settings);
    
    /* ADC 1 */
    SensEdu_ADC_Init(&adc1_settings);
    SensEdu_ADC_Enable(adc1);

    /* ADC 2 */
    SensEdu_ADC_Init(&adc2_settings);
    SensEdu_ADC_Enable(adc2);

    lib_error = SensEdu_GetError();
    while (lib_error != 0) {
        handle_error();
    }
}

/* -------------------------------------------------------------------------- */
/*                                    Loop                                    */
/* -------------------------------------------------------------------------- */

void loop() {
	SenseduBoard* main_obj_ptr = &SenseduBoardObj;
    // Measurement is initiated by the signal from computing device (matlab script)
    static char serial_buf = 0;
    
    // Measurement is initiated by signal from computing device
    while (1) {
        while (Serial.available() == 0); // Wait for a signal
        serial_buf = Serial.read();
        if (serial_buf == 't') {
            break; 
        }
    }
    
    // Start dac->adc sequence
    SensEdu_DAC_Enable(dac_channel);
    while(!SensEdu_DAC_GetBurstCompleteFlag(dac_channel)); // wait for dac to finish sending the burst
    SensEdu_DAC_ClearBurstCompleteFlag(dac_channel); 
    
    // Start ADCs
    SensEdu_ADC_Start(adc1);
    SensEdu_ADC_Start(adc2);

    // Wait for the data from ADC1
    while(!SensEdu_ADC_GetTransferStatus(adc1));
    SensEdu_ADC_ClearTransferStatus(adc1);

    // Wait for the data from ADC2
    while(!SensEdu_ADC_GetTransferStatus(adc2));
    SensEdu_ADC_ClearTransferStatus(adc2);

    // Calculating distance for each microphone
    static uint32_t distance[adc1_mic_num + adc2_mic_num];
    for(uint8_t i = 0; i < adc1_mic_num; i++) {
        get_channel_data(adc1_data, main_obj_ptr->channel_buffer, STORE_BUF_SIZE, adc1_mic_num, i);
        process_data(main_obj_ptr->processing_buffer, STORE_BUF_SIZE, main_obj_ptr->channel_buffer, STORE_BUF_SIZE, main_obj_ptr->ban_flag);
        distance[i] = calculate_distance(main_obj_ptr->processing_buffer, STORE_BUF_SIZE, ACTUAL_SAMPLING_RATE);
    }
    for(uint8_t i = 0; i < adc2_mic_num; i++) {
        get_channel_data(adc2_data, main_obj_ptr->channel_buffer, STORE_BUF_SIZE, adc2_mic_num, i);
        process_data(main_obj_ptr->processing_buffer, STORE_BUF_SIZE, main_obj_ptr->channel_buffer, STORE_BUF_SIZE, main_obj_ptr->ban_flag);
        distance[adc1_mic_num + i] = calculate_distance(main_obj_ptr->processing_buffer, STORE_BUF_SIZE, ACTUAL_SAMPLING_RATE);
    }

    // Sending the distance measurements
    for (uint8_t i = 0; i < (adc1_mic_num + adc2_mic_num); i++) {
        Serial.write((const uint8_t *) &distance[i], 4);
    }

    // check errors
    lib_error = SensEdu_GetError();
    while (lib_error != 0) {
        handle_error();
    }
}

void process_data(float* buf, const uint16_t buf_size, uint16_t* ch_array, const uint16_t ch_array_size, uint8_t ban_flag) {

    /* --------------------- RESCALED, FILTERED, NO COUPLED --------------------- */
    // Rescale from [0, (2^16-1)] to [-1, 1] and filter around 32 kHz
    clear_float_buf(buf, buf_size);
    rescale_adc_wave(buf, ch_array, ch_array_size);
    filter_32kHz_wave(buf, buf_size);
    if (ban_flag == 1) {
        remove_coupling(buf, c_banned_sample_num);
    } 
    /* ---------------------------------- XCORR --------------------------------- */
	custom_xcorr(buf, dac_wave, buf_size);
    
}

void transfer_serial_data(uint16_t* data, const uint16_t data_length, const uint16_t chunk_size_byte) {
    for (uint16_t i = 0; i < (data_length*2); i += chunk_size_byte) {
        uint16_t transfer_size = ((data_length*2) - i < chunk_size_byte) ? (data_length*2 - i) : chunk_size_byte;
        Serial.write((const uint8_t *) data + i, transfer_size);
    }
}

void transfer_serial_data_float(float* data, const uint16_t data_length, const uint16_t chunk_size_byte) {
    for (uint16_t i = 0; i < (data_length*4); i += chunk_size_byte) {
        uint16_t transfer_size = ((data_length*4) - i < chunk_size_byte) ? (data_length*4 - i) : chunk_size_byte;
        Serial.write((const uint8_t *) data + i, transfer_size);
    }
}

void handle_error() {
    // serial is taken by matlab, use LED as indication
    digitalWrite(error_led, LOW);
}

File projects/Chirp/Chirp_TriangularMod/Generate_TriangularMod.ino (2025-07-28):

const uint32_t x = 5; // sin LUT resolution
const float Pi = 3.14159; // pi

// Generate the chirp signal
void generateTriangularChirp(uint16_t* array) {

    float lut_sin[90 * x]; // Quarter-wave LUT for sine values
    float vChirp; // Chirp signal value
    int n = round(samples_int/2);
    float phase_deg; // Phase angle in degrees
    float phase_rad; // Phase angle in radians
    float phase_deg_wrapped; // Wrapped phase angle
    float sK = 2*(END_FREQUENCY - START_FREQUENCY) / CHIRP_DURATION; // Chirp rate

    // Generate the quarter-wave sine LUT
    for (int i = 0; i < 90 * x; i++) {
        phase_deg = (float)i * 90.0 / (90 * x); // Phase angle in degrees
        phase_rad = phase_deg * Pi / 180.0; // Phase angle to radians
        lut_sin[i] = sin(phase_rad-Pi/2); // Store sine value in the LUT
    }

    // Generate the chirp signal
    for (int i = 0; i < n; i++) {
        phase_rad = 2.0 * Pi * (0.5 * sK * (i - 1) / fs + START_FREQUENCY) * (i - 1) / fs; // Phase angle in radians
        phase_deg = phase_rad * 180.0 / Pi; // Phase angle to degrees
        phase_deg_wrapped = fmod(phase_deg, 360.0); // Wrap phase angle to 0-360 degrees

        if (phase_deg_wrapped <= 90) {
            vChirp = lut_sin[(int)(phase_deg_wrapped)* x+1] * 2048 + 2048;
        } else if (phase_deg_wrapped <= 180) {
            vChirp = -lut_sin[(int)(180.0 - phase_deg_wrapped) * x+1] * 2048 + 2048;
        } else if (phase_deg_wrapped <= 270) {
            vChirp = -lut_sin[(int)(phase_deg_wrapped - 180.0) * x+1] * 2048 + 2048;
        } else {
            vChirp = lut_sin[(int)(360.0 - phase_deg_wrapped)* x+1] * 2048 + 2048;
        }
        
        array[i] = (uint16_t)vChirp;
    }

    for (int i = n; i < samples_int; i++) {
        array[i] = array[samples_int - i-1];
    }
}

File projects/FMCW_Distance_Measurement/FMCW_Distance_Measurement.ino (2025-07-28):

#include <SensEdu.h>
//NOTE : 

/* -------------------------------------------------------------------------- */
/*                                User Settings                               */
/* -------------------------------------------------------------------------- */

#define CHIRP_DURATION          0.04   // Duration of the chirp (in seconds)
#define START_FREQUENCY         30500   // Start frequency (in Hz)
#define END_FREQUENCY           35500  // Stop frequency (in Hz)

/* -------------------------------------------------------------------------- */
/*                                 Settings                                   */
/* -------------------------------------------------------------------------- */

// ADC Sampling
const uint16_t mic_data_size = 14400; // ADC buffer size, must be a multiple of 16
__attribute__((aligned(__SCB_DCACHE_LINE_SIZE))) uint16_t adc_dac_data[mic_data_size]; // cache aligned
__attribute__((aligned(__SCB_DCACHE_LINE_SIZE))) uint16_t adc_mic_data[mic_data_size]; // cache aligned

// ADC-DMA Hardware Settings
ADC_TypeDef* adc_dac = ADC3;
ADC_TypeDef* adc_mic = ADC1;
const uint8_t mic_num = 1;
uint8_t adc_dac_pins[mic_num] = {A8}; 
uint8_t adc_mic3_pins[mic_num] = {A1};

SensEdu_ADC_Settings adc1_settings = {
    .adc = adc_dac,
    .pins = adc_dac_pins,
    .pin_num = mic_num,

    .conv_mode = SENSEDU_ADC_MODE_CONT_TIM_TRIGGERED,
    .sampling_freq = 250000,
    
    .dma_mode = SENSEDU_ADC_DMA_CONNECT,
    .mem_address = (uint16_t*)adc_dac_data,
    .mem_size = mic_data_size
};

SensEdu_ADC_Settings adc2_settings = {
    .adc = adc_mic,
    .pins = adc_mic3_pins,
    .pin_num = mic_num,

    .conv_mode = SENSEDU_ADC_MODE_CONT_TIM_TRIGGERED,
    .sampling_freq = 250000,
    
    .dma_mode = SENSEDU_ADC_DMA_CONNECT,
    .mem_address = (uint16_t*)adc_mic_data,
    .mem_size = mic_data_size
};

//DAC settings
static uint8_t increment_flag = 1; // Run time modification flag
const float fs =  10 * END_FREQUENCY; // Sampling frequency
const float samples = fs * CHIRP_DURATION; // Number of samples
const uint32_t samples_int = (uint32_t)samples;
static SENSEDU_DAC_BUFFER(lut, samples_int); // Buffer for the chirp signal

SensEdu_DAC_Settings dac1_settings = {
    DAC_CH2, fs, (uint16_t*)lut, samples_int,
    SENSEDU_DAC_MODE_CONTINUOUS_WAVE, 1
};


// Error Handling
uint8_t error_led = D86; // Error indicator LED pin
uint32_t lib_error = 0;  // Tracks library errors
bool dac_data_sent = false; // To track whether DAC LUT was sent to MATLAB

/* -------------------------------------------------------------------------- */
/*                              Functions                                     */
/* -------------------------------------------------------------------------- */

// Function to send an array over Serial in 32-byte chunks
void serial_send_array(const uint8_t* data, size_t size) {
    const size_t chunk_size = 32;
    for (size_t i = 0; i < size / chunk_size; i++) {
        Serial.write(data + chunk_size * i, chunk_size);
    }
}

// Function to handle errors
void handle_error() {
    digitalWrite(error_led, LOW); // Turn on error LED
    while (1) {
        // Remain in this state if an error occurs
    }
}

/* -------------------------------------------------------------------------- */
/*                                   Setup                                    */
/* -------------------------------------------------------------------------- */
void setup() {
    // Initialize Serial Communication
    Serial.begin(115200);
    while(!Serial);

    // Initialize ADC
    SensEdu_ADC_Init(&adc1_settings);
    SensEdu_ADC_Init(&adc2_settings);
    SensEdu_ADC_Enable(adc_dac);
    SensEdu_ADC_Enable(adc_mic);

    // Generate the chirp signal
    generateSawtoothChirp(lut);

    // Print the chirp signal LUT
    Serial.println("start of the Chirp LUT");
    for (int i = 0 ; i < samples_int; i++) { // loop for the LUT size
        Serial.print("value ");
        Serial.print(i+1);
        Serial.print(" of the Chirp LUT: ");
        Serial.println(lut[i]);
    }
    
    // Initialize DAC
    SensEdu_DAC_Init(&dac1_settings);
    SensEdu_DAC_Enable(DAC_CH2);

    // Setup Error LED
    pinMode(error_led, OUTPUT);
    digitalWrite(error_led, HIGH); // Turn off (active low)

    // Check for errors
    lib_error = SensEdu_GetError();
    if (lib_error != 0) {
        handle_error();
    }
}

/* -------------------------------------------------------------------------- */
/*                                    Loop                                    */
/* -------------------------------------------------------------------------- */
void loop() {
    static char serial_buf = 0;

    // Wait for trigger command ('t') from MATLAB
    while (1) {
        while (Serial.available() == 0);
        serial_buf = Serial.read();

        if (serial_buf == 't') { // First trigger detected
            break;
        }
    }
    
    // Start ADC Data Acquisition
    SensEdu_ADC_Start(adc_dac);
    SensEdu_ADC_Start(adc_mic);

    // wait for the data and send it
    while(!SensEdu_ADC_GetTransferStatus(adc_dac));
    SensEdu_ADC_ClearTransferStatus(adc_dac);

    while(!SensEdu_ADC_GetTransferStatus(adc_mic));
    SensEdu_ADC_ClearTransferStatus(adc_mic);


    // Send ADC data (16-bit values, continuously)
    uint32_t adc_byte_length = mic_data_size * 2; // ADC data size in bytes
    Serial.write((uint8_t*)&adc_byte_length, sizeof(adc_byte_length));  // Send size header
    serial_send_array((const uint8_t*)adc_dac_data, adc_byte_length);       // Transmit ADC3 data
    serial_send_array((const uint8_t*)adc_mic_data, adc_byte_length);       // Transmit ADC1 data (Mic2 data)

    // Check for errors during the process
    lib_error = SensEdu_GetError();
    if (lib_error != 0) {
        handle_error();
    }
}

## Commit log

2025-01-07 timer delay frequency fix + example
2025-01-07 1ch adc readings with a timer trigger example
2025-01-08 Implementation of Low-pass filter
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2025-01-08 Revert "Arduino Library Folder"
    This reverts commit 95e077ff24510c91b5def60c1da9df8c0316bbde.
    Revert "Arduino Library Folder"
    This reverts commit 95e077ff24510c91b5def60c1da9df8c0316bbde.
2025-01-13 starting work on dma
2025-01-14 first dma results with possible DCache problems
2025-01-14 messy, but first fully working dma
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2025-01-17 Finished Basic UltraSound example using SensEdu library + DAC tests (bug with wave cut still occurs)
    [Send_Burst_Sine.ino]
2025-01-23 successful constant dac wave with dma
2025-01-23 dac & dma rewritten to match new style + descriptor for dac
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2025-01-24 timer management is included in dac calls
2025-01-24 restructured adc.c to match new style. all dma and timers are now invoked inside init/enable/start functions of adcs. Read_ADC_1CH if functional with new style
2025-01-27 struct for each adc1/2/3 inside dma.c
2025-01-28 adc number as input for transfer status
2025-01-28 adc1 and adc2 work at the same time (but with common timer)
2025-01-29 Example for serial communication using 2 channels of 1 ADC.
2025-01-30 github button and night\light mode switch
2025-01-31 Example of sending dealing with double channel adc data on mcu
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2025-02-02 improved buttons + pics (FOUC problem still persists)
2025-02-03 script for measuring adc sampling rate
2025-02-06 added cleancache before dma init
2025-02-11 dac dma cache coherence fix moved inside the library + flexible sizes for buffers
2025-02-12 Initial FMCW Arduino example
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2025-02-14 adc docu init, start, enable, disable
2025-02-17 developer notes for timers finished
2025-02-17 adc functions section is finished
2025-02-17 updated adc init with warning for proper call order
2025-02-17 adc related dma interrupts moved to adc.c
2025-02-17 adc3 interrupts fix; cpu polling bug persists
2025-02-18 Triangle modulated chirp example in Arduino now initializes MEMS microphones to perform measurement in MATLAB.
2025-02-20 sample docu page for pcb
2025-02-20 KiCad Files
    [AD8426ACPZ-R7.step, BLM31KN471SH1L.step, DPS310XTSA1.step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]
2025-02-25 some of adc examples + basic structure for other pages
2025-02-26 docu: dma examples for ADC
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2025-02-28 Chirp doc v1.0 finished. Added sampling freq error to dac.c & error message for user in Chirp_SawtoothMod.ino
    [Chirp_SawtoothMod.ino]
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2025-02-28 schematics link fix
2025-02-28 filtering the dac signal
2025-02-28 fix: schematics.pdf wrong case for filename
2025-02-28 adc errors
2025-02-28 timer errors
2025-02-28 Adjusted user error message in Chirp_SawtoothMod.ino & Chirp_TriangularMod.ino
    [Chirp_SawtoothMod.ino, Chirp_TriangularMod.ino]
2025-03-03 Chirp doc v1.1. Small adjustment to Chirp_TriangularMod.ino error message
    [Chirp_TriangularMod.ino]
2025-03-05 Calculation of PSC and ARR for precise setting of ADC sampling rate.
2025-03-06 Updated ADC Sampling Rate Docu
2025-03-06 Checking real ADC sampling rate and finding the max value.
2025-03-07 Real time ADC data and spectrum available, updated ultrasound_distance_measurement with new SensEdu_ADC_GetTransferStatus instead of old SensEdu_DMA_GetADCTransferStatus function
2025-03-07 Real time Tx and Rx signals plot and spectrum using 2 ADCs. ADC1 receiving Tx signal from 2nd Arduino board and ADC2 receiving Rx signal with mic.
2025-03-10 Generation of filtered DAC signal to simulate better speaker signal for better xcorr results.
2025-03-11 FMCW Radar 1st distance measurements working using 2 SensEdu Boards. Added all useful modules : SendDACdata.ino, DAC_data.m, Plot_Tx_Rx.m
2025-03-21 docu: PCB new syntax for pictures + spacings fix
2025-03-24 Steps for how to change ADC sampling rate in the ultrasound project
2025-03-24 docs: adc picture white background
2025-03-25 docu: PCB table of contents
2025-03-25 docu: pcb pic alignment fix
2025-03-26 docu: timer callout -> alert
2025-04-23 Don't put extern "C" around includes
    Only put extern "C" around the prototypes of functions defined within
    each header.
    If the first inclusion of a C++ library happens within an
    extern "C" block, it can cause linker errors as the code now references
    an unmangled symbol, but the real symbol is mangled by c++.
2025-05-09 1x4 jumper to mini jack pcb template
    [MiniJack2Jumper.kicad_pcb, MiniJack2Jumper.kicad_sch]
2025-05-09 added header + BOM
    [EMG_Total_BOM.xlsx, MiniJack2Jumper.kicad_pcb, MiniJack2Jumper.kicad_sch]
2025-05-12 finiished mini jack to 1x4 jumper pcb
    [MiniJack2Jumper-BOM.csv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]
2025-05-12 rename to EMG-BioInputs
    [EMG-BioInputs-BOM.xlsx, MiniJack2Jumper-BOM.csv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]
2025-05-12 EMG ADC sketch template
2025-05-14 updated manufacturing files
    [MiniJack2Jumper-B_Cu.gbr, MiniJack2Jumper-B_Mask.gbr, MiniJack2Jumper-B_Paste.gbr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]
2025-05-14 Fixed SensEdu lib ADC buffer size calculation bug
2025-05-14 Finished EMG arduino sketch
2025-05-20 ADC data transfer fix
    [EMG-BioInputs.ino]
2025-05-23 Fixed chirp discontinuity for sawtooth modulation
    [Generate_SawtoothMod.ino]
2025-05-23 Chirp triangular modulation supports large LUT & fixed chirp duration logic
    [Chirp_TriangularMod.ino, Generate_TriangularMod.ino]
2025-05-26 updated quick note on capacitive input that caused spikes on first ADC readings
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2025-05-28 filtering cut and plotting shift fix + reconstruction update
    [EMG-BioInputs.ino]
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2025-05-30 souls tested working LMC for attack button
2025-06-06 Fixed ADC conflict with FMCW radar
    [FMCW_Distance_Measurement.ino]
2025-06-13 Internal firmware error notification for MATLAB
    [EMG-BioInputs.ino]
2025-06-13 Added XENSIV_Digital_Pressure_Sensor library to use with DPS310 barometric pressure sensor
2025-06-13 Added XENSIV pressure sensor github link to acknowledgments
2025-06-13 renaming driver to old version
2025-06-13 Rewritten data acquisition with smart buffering for better filtering
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2025-06-25 MATLAB & Arduino scripts for single board FMCW radar distance measurement in progress
2025-07-21 Pressure sensor library update
2025-07-21 FMCW distance measurement with single board update
2025-07-21 Updated Arduino FMCW script and documentation
2025-07-24 Added SHT35 Board PCB files and Weather_Station example updated
    [SHT35-DIS-B2.5KS.STEP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]
2025-07-24 Removed SHT35 PCB backups
2025-08-01 EMG docs: electrode connectivity setup draft
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2025-08-06 copy @azrat6 ultrasonic ranging as template for wifi gui add-on
2025-08-08 detailed ultrasound processing fixed from experimental adjustment mode to just sending the whole thing like in the past
    [ADC_signal_processing.ino, UltraSound-WiFi-GUI.ino]
2025-08-09 EMG docs: signal processing capacitance and buffer draft
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2025-08-11 one mic detailed data for ultrasonic wifi gui projects
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2025-08-12 basic ultrasound wifi: small wiki corrections + added couple of pictures
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2025-08-13 pwm: template for new lib periph and docs
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2025-08-13 docs: updated main page for library with pwm periph
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2025-08-19 pwm: fix default high vs low bug
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2025-08-20 pwm: polarity bug correction
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2025-08-22 pwm: docs final small corrections
2025-08-27 lib: timer frequency calculation rewritten + added delays in nanoseconds. New timers achieve only 550ns of CPU overhead.
2025-09-08 Change in ADC and DAC docu in the sampling rate paragraphs.
2025-09-10 removed duplicate arduino wifi sketch + minor corrections
    [UltraSound-WiFi-GUI.ino]
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2025-09-10 adapted interface to work with detailed arduino sketch while still showing only raw data
2025-09-11 lib: new flexible adc buffers with auto alignment and internal size adjustments + updated examples
2025-09-11 lib: cleaned up basic wifi example + replacements with new adc buffers + size of 2000 is now possible
    [UltraSound-WiFi-GUI.ino]
2025-09-12 lib: documentation covering the new adc buffer declaration
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

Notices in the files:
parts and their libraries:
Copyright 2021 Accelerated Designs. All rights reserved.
